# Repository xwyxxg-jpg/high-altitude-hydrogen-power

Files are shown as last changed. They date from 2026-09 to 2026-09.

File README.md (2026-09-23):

# 高寒高海拔 5 kW 氢能移动电源

**High-altitude & cold-climate hydrogen power — 开放设计与研发进度**

面向 −30°C 环境的5 kW净输出燃料电池电源研究项目。当前V2采用纯气态储氢，开展电堆、辅机、散热和氢量的联合计算；历史双储氢方案与R12装配保留为研究记录。

**进度快照：2026-09-23 · 当前计算：V2纯气态储氢 · 历史装配：R12。**
现有结果未证明已达到 5 kW 净输出、120 s 低温启动或寿命指标。

## 最新：V2纯气态储氢联合计算

- [第二版设计与稳态联合求解](designs/v2-gaseous/第二版设计.md)
- [−30℃暖堆稳态、冷液水力与启动热量计算](designs/v2-gaseous/第二版设计_负30度补充计算.md)
- [计算入口、依赖与校验方法](designs/v2-gaseous/README.md)

在暂定4000 m、35℃、4 h任务下，5 kW净输出的基准解需要约6.20 kW堆毛功率、5.20 kW液冷排热及66.2 L气瓶水容积；布局先按2×40 L预留。固定散热器在−30℃环境且电堆已升温时，计入局部伴热及风机预算后毛功率约5.72 kW。上述均为带假设的计算，不是供应商保证或实测；冷浸启动尚未验证。

多项不利假设组合需要约8.15 kW、97.85 A，超过参考7.1 kW/80 A电堆能力，已标记不可行。历史R12 CAD并未按V2重建，不能用于证明V2尺寸。

## 历史R12装配快照

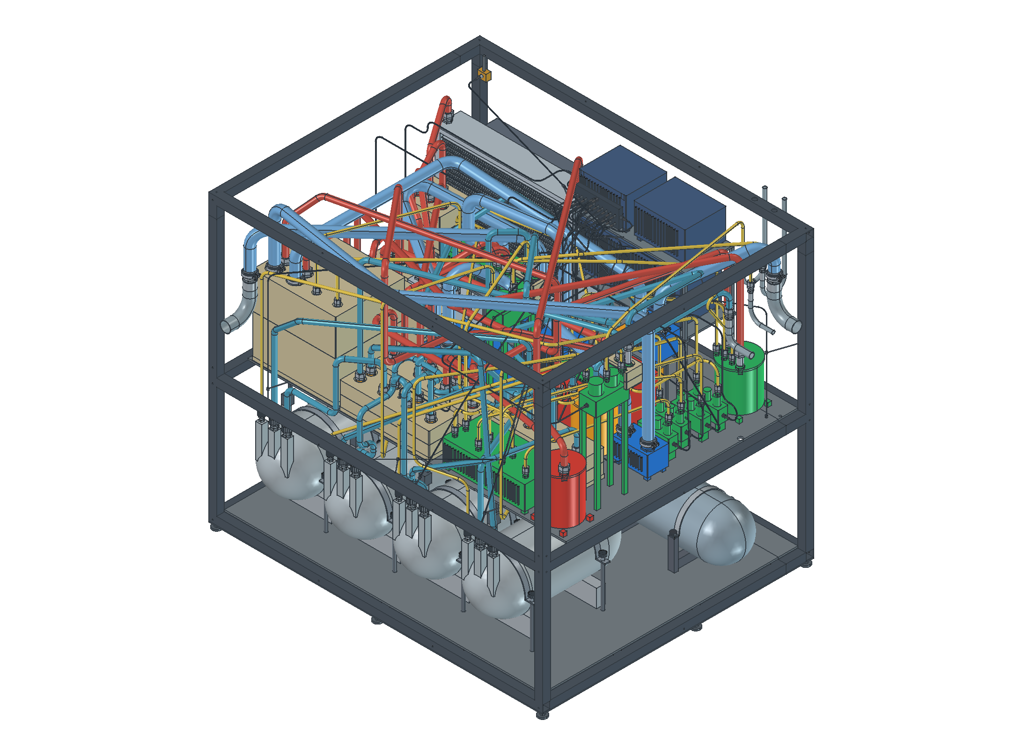
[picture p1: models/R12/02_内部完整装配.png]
R12 内部完整装配


## 历史双储氢方案进展

| 工作 | 已有成果 | 仍待完成 |
|---|---|---|
| 系统设计 | 双氢源、双液路、燃料电池与电池混合供电方案 | 电堆和辅机参数冻结、版本间参数统一 |
| 计算 | 质量/能量/氢耗、海拔工况、PCT 外推与分床热模型源码 | 材料实测参数、模型标定及系统动态仿真 |
| R12 三维布局 | 1011 个零件对象、1203 个实体；外包络约 1724×1458.2×1505 mm | 安装顺序、维护路径与支承强度复核 |
| 管路和线束 | 69 条圆弧管路、21 条线束；126 个内部管端连接检查通过 | 工艺与实物装配验证 |
| 静态几何 | 既有检查记录中超 0.1 mm³ 干涉为 0；STEP 回读实体有效 | 不等同于压力、强度或制造合格 |
| 工具空间 | 112 个接口已筛查，40 个找到无碰撞姿态 | 72 个接口受限；六只容器完整取出路径待复核 |
| 电气设计 | R12 低压电气图、阀门统计 | 与采购定型器件和最终功率基线一致化 |

几何数据来自项目现有 R12 检查记录，本次公开整理没有重新运行 CAD 求解器。

## 研究时间线

| 时间（北京时间） | 思考与决策 | 搜索、计算或校核带来的结果 |
|---|---|---|
| 7 月 18–22 日 | 比较储氢路线，厘清混合能源与冷启动 | 区分局部 CFD 与整机控制；粗算中冷器温升、分水器产水量 |
| 7 月 27 日–8 月 17 日 | 图纸应表达真实连接与控制关系 | P&ID 连通/排版检查；低压电气引脚、CAN 和硬线急停审查 |
| 8 月 30 日–9 月 6 日 | 从容量、耗氧、余热推导零件尺寸 | 空气加热负荷和光管体积被重新修正；发现续航与轻量化冲突 |
| 9 月 9 日 | 查论文、专利和器件，形成完整概念设计 | 70 节方案、质量/能量模型与 FreeCAD 概念装配 |
| 9 月 10–11 日 | 改固态∶气态为 6∶4，压缩布局 | R10→R12；几何检查通过，但 R12 仍有 72 个工具空间受限接口 |
| 9 月 12–14 日 | 检查保温冷启动、重量及报告参数自洽 | 45 min 与 120 s 的定义冲突；区分 70/53/55 节及不同容量版本 |
| 9 月 15 日 | 阀门不能只按电气支线计数 | 逐项核对 14 个对象、52 个外部流体接口 |
| 9 月 19 日 | 公开进展与研究过程 | 重跑概念计算、发布模型及证据，保留未验证项 |

[阅读完整时间线：你的提问与选择、检索来源、计算结果和后续修正](docs/TIMELINE.md)。历史讨论结果按当时工况记录，不等同于实测性能。

## 阅读入口

- [R12 修改与检查说明](models/R12/R12_设计修改与检查说明.md)：当前装配范围、检查方法与未闭合问题。
- [几何与安装校核数据](models/R12/几何与安装校核数据.json)及[接口工具空间检查](models/R12/接口工具空间检查.csv)：可检查的结果记录。
- [9 月 9 日概念设计](docs/concept-design-20260909.md)、[BOM 与接口表](docs/bom-and-interfaces.md)、[参考来源](docs/references.md)。
- [版本与参数边界](docs/STATUS.md)：解释概念设计和 R12 装配的区别。
- [项目思考、检索与验证时间线](docs/TIMELINE.md)：按日期记录方案取舍、搜索依据、计算结果和验证边界。
- [FreeCAD 可编辑模型](models/R12/3D燃料电池模型.FCStd) · [STEP 交换模型](models/R12/R12_紧凑分层_转角修复.step)。
- [电气图源文件](diagrams/electrical-R12.drawio) · [电气图预览](diagrams/electrical-R12.png)。

## 历史双储氢系统关系

```mermaid
flowchart LR
  G[启动气瓶] --> H[氢气调压与供给]
  M[四罐固态储氢] --> H
  H --> FC[液冷 PEMFC]
  A[空气供给与加热] --> FC
  FC --> DC[单向 DC/DC]
  DC --> BUS[48 V 母线与负载]
  B[启动电池] <--> BDC[双向 DC/DC]
  BDC <--> BUS
  FC --> T[主冷却与隔离换热]
  T --> M
  T --> R[散热器]
```

功能图用于阅读；DC/DC 类型、压力与容量应按相应版本文件核对。

## 复算历史概念设计

需要 Python 3.10+ 和 Matplotlib。以下命令在仓库根目录执行：

```bash
python -m venv .venv
# Windows: .venv\Scripts\activate
# macOS/Linux: source .venv/bin/activate
python -m pip install -r requirements.txt
python tools/calculate.py
```

脚本更新 `calculations/parameters.json`，生成分床温度数据及两幅图，并检查能量守恒残差。图表原脚本使用 Microsoft YaHei；未安装该字体的平台可能出现中文字体提示。

计算对应 **2026-09-09 的 70 节概念方案**：156 A、0.65 V/节时毛功率 7.098 kW；变换效率 96%、辅机 1.30 kW 时净功率估算 5.514 kW。该结果不代表实测性能，也不能直接替代 R12 的储氢容量分配。

## 下一步（V2优先）

- [ ] 取得参考电堆高原极化、低温启动和冷却液许可数据。
- [ ] 用泵、风机、散热器及电池实测曲线替换V2假设。
- [ ] 完成纯气态储氢P&ID、接口表和真实器件CAD。

以下为历史R12路线尚未闭合的工作：

- [ ] 统一 R12 装配、技术报告、电气图与概念计算的参数基线。
- [ ] 调整受限阀组和管廊，复核 72 个接口的工具进入路径。
- [ ] 完成储氢模块整件取出路径及 R12 分层支承强度校核。
- [ ] 取得材料 PCT/动力学及阀泵、电堆、高原空气系统的供应商数据。
- [ ] 完成 Fluent 基准/强化床对比和整机低温动态仿真。
- [ ] 通过台架验证冷启动、净功率、热利用率及耐久目标。

## 开源范围

项目原创代码、文档和设计文件采用 [MIT License](LICENSE)。第三方商标、专利及引用资料的权利仍归其权利人；本仓库仅保留来源引用，不分发原始厂商 CAD 库、下载论文和内部参考资料。

这是研究与概念设计资料，不能直接作为压力容器制造或氢系统运行依据。欢迎通过 Issue 提交参数来源、计算修正和装配空间建议；见 [贡献说明](CONTRIBUTING.md)。

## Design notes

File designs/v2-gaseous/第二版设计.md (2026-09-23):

# 第二版设计：纯气态储氢5 kW高寒移动电源

版本：V2.0概念计算版  
日期：2026-09-23  
设计负责人：邢武岳  
状态：完成条件性稳态联合求解；尚未完成供应商选型、低温动态验证及真实三维装配。

2026-09-23补充：[−30℃参数变化与启动计算](第二版设计_负30度补充计算.md)。保留本文件+35℃散热设计点，新增同一硬件在−30℃环境的暖堆稳态、冷液水力敏感性、气瓶温压和启动热量预算；不将暖堆结果当作冷启动成功。

## 1. 本版目标与边界

本版取消固态储氢床、床体供热支路和气固切换机构，采用采购PEM电堆、纯气态储氢、空气供给、单一电堆液冷回路、DC/DC和辅助电池。

**唯一已明确的功率硬约束是对外净输出5 kW。**电堆毛功率必须支付转换损耗和全部计入模型的辅机耗电。旧报告的节数、气固比例、整机85 kg、170 L以及120 s建立气路的定义均不继承。

| 输入 | 本版采用 | 性质 |
|---|---|---|
| 对外连续功率 | 5 kW DC | 用户要求；若改AC需增加逆变损耗 |
| 输出母线 | 48 V，额定约104.2 A | 工程假设，未冻结 |
| 满载续航 | 4 h | 沿用工作假设，可调整 |
| 冷启动环境 | −30℃完全冷浸 | 目标工况，冷浸时间待定 |
| 冷启动时间 | 尽可能120 s；分别记录电池对外供电和电堆建立净输出 | 未证明 |
| 稳态散热工况 | 4000 m、+35℃ | 本版设计假设；不代表电堆已有高原认证 |
| 气瓶额定研究点 | 35 MPa绝压、15℃均温充装状态 | 容量计算参考点；实际充装遵守认证瓶参数 |
| 最低可用压力 | 2 MPa绝压、−30℃ | 调压器输入下限假设 |
| 启动额外耗氢 | 0.03 kg | 预算占位，待动态积分 |
| 储备 | 任务结束保留初始可用氢的10% | 预算假设 |

“5 kW连续输出”不包括电池长期补足电堆功率缺口。电池启动后消耗的电量还需要额外发电余量恢复；本版4 h预算没有包含整段运行中的电池充电任务。

## 2. 功能拓扑

```text
认证气瓶A/B → 各自隔离/切断/安全附件 → 分级调压 → 低压氢路 → 电堆阳极
                                                          ↓
                                               排水/吹扫 → 规定安全排口

空气滤芯 → 鼓风机 → 必要的调温/加湿 → 阴极 → 冷凝水管理/排气

电堆 → 小循环/旁通阀 → 散热器 → 主泵 → 电堆
         ↑ 保温与启动加热       ↑ 膨胀/排气/净化支路

电堆 → 单向DC/DC → 48 V母线 → 外部负载
辅助电池 ↔ 双向DC/DC ────┘
独立安全链/控制器 → 阀、风机、泵、加热器、DC/DC
```

高压排放、低压工艺吹扫和阴极排气的压力、流量与背压限制不同，不能默认汇成同一根细管。图中仅定义功能，不作为施工P&ID。

## 3. 未知量与闭合条件

设计问题本来欠定：没有堆极化曲线、泵风机图谱、散热器性能面和气瓶型号，5 kW不能唯一决定所有部件尺寸。本版引入显式假设，求得一组可复算的初步解，再做敏感性分析。

主未知量为：

- 电堆电流 I；
- 散热器迎风面积 A；
- 冷却液质量流量 m_c。

由三项等式联合求解：

1. 净电功率等于5000 W；
2. 散热器排热等于进入冷却液的热量；
3. 冷却液温升等于5 K。

氢耗、空气流量、风机/泵功耗、气瓶水容积和管径从解中派生。电池、电控箱等缺少定型资料，只给预算及空间占位，不假称由三条方程唯一求出。

### 3.1 采购电堆参考平台

以2026-09-21归档的H-WCS-SP-7K为参考：119节、活性面积200 cm²、80 A、约90 V、公开功率7.1 kW、外形242×200×550 mm、约28 kg。采用现有平台只是为了提供实体尺度。

公开工作环境5～35℃，测试条件65℃、常压及阴阳极100%RH。**这些数据不证明4000 m、60℃冷却出口或−30℃启动时仍有同样性能。**本模型单节0.75 V是基准假设，不是实测极化曲线；0.70 V用于敏感性分析。若低温/高原工作点下降，需要替换输入重算。

### 3.2 功率与反应物方程

```text
Pstack = N × Vcell × I
5000 = ηDC × Pstack − Pblower − Pfan − Ppump − Pfixed
mH2,reaction = N × I × MH2 / (2F)
mH2,fresh = mH2,reaction / ηH2
mair = N × I × MO2 / (4F) × λair / 0.232
```

N=119，ηDC=0.96，ηH2=0.97，λair=2.2，固定辅助电功率100 W。97%是新鲜氢利用率假设，不是阳极流道计量比；若采用氢循环，还要增加循环装置损耗，若死端吹扫则需重新积分排氢。

鼓风机功耗用等熵压缩估计，入口取当地大气压，基准阴极总压升15 kPa，总效率50%。该压升需由滤芯、管路、加湿器、电堆和背压件分项替换；还需要膜两侧差压约束，不能据此直接设置阳极压力。

### 3.3 热管理与液路方程

```text
Qreaction,HHV ≈ N × I × (1.481 − Vcell)
Qcoolant = 0.85 × Qreaction,HHV + Ppump
mc × cp,c × (60−55) = Qcoolant
Δpc = 80 kPa × [液体体积流量 / (20 L/min)]²
Ppump = 液体体积流量 × Δpc / 0.30
```

1.481 V为热中性电压近似常数。85%热量进入冷却液、15%分配给尾气水焓和环境，是尚未测量的分配假设。避免把全部HHV热量与水蒸气焓重复计入。泵电功率保守计入液体，需实机热平衡修正。

暂用低温冷却液温热物性cp=3300 J/(kg·K)、ρ=1060 kg/m³；不等于已指定冷却液型号或确认−30℃黏度/电导率。二次阻力曲线只适合本次温热估算，不能外推到冷浸启动。

DC/DC损耗、风机/鼓风机电机热及电控热没有全部进入电堆冷却回路，应通过各自通风/散热独立排出。整机风道还需考虑热空气回流。

### 3.4 散热器方程

采用ε–NTU逆流基式并乘0.85布局修正，用于初步筛选，不代表实际交叉流散热器。

```text
体积风量 = 3 m/s × A
UA = 1000 W/(m²·K) × A
Qradiator = 0.85 × ε(NTU,Cr) × Cmin × (60−35)
Pfan = 180 Pa × 体积风量 / 0.35
```

这里1000 W/(m²·K)是以**迎风面积**归一的假设UA系数，不是翅片表面对流换热系数。厚度、翅片密度、空气阻力与UA实际相互耦合，必须用同一台散热器性能数据替换，不能独立拼最优参数。

## 4. 基准联合解

| 项目 | 解 |
|---|---:|
| 对外净输出 | 5000 W |
| 电堆毛功率 | 6200 W |
| 电堆工作电压/电流 | 89.25 V / 69.47 A |
| DC/DC损耗 | 248 W |
| 阴极鼓风机 | 259 W |
| 散热风机 | 530 W |
| 冷却泵 | 63 W |
| 固定辅机 | 100 W |
| HHV口径反应热 | 6043 W |
| 电堆尾气/环境热分配假设 | 906 W |
| 冷却液排热（含泵） | 5200 W |
| 冷却流量 | 17.84 L/min |
| 温热液路压降/扬程 | 63.6 kPa / 6.12 m |
| 散热器迎风面积 | 0.344 m² |
| 散热器实际空气体积流量 | 3712 m³/h |
| 散热器出风温度 | 约42.2℃ |
| 反应空气质量流量 | 6.50 g/s |
| 反应空气入口实际体积流量 | 33.6 m³/h（4000 m、35℃） |
| 理论反应氢耗 | 0.311 kg/h |
| 新鲜氢耗（97%利用率） | 0.321 kg/h |
| 反应产水 | 2.78 kg/h，不代表全部在同一分水器收集 |

**功率核对：6200×0.96−259−530−63−100≈5000 W。**

散热器风量与反应空气流量不是一个量级，风机不能混用。散热器面积及风量明显影响寄生功耗，不能把散热风机简单按几十瓦占位。

## 5. 纯气态储氢容量与外包络

使用CoolProp真实氢气状态方程，不用35 MPa理想气体近似：

```text
ρfill = ρH2(15℃, 35 MPa绝压) = 23.995 kg/m³
ρresidual = ρH2(−30℃, 2 MPa绝压) = 1.969 kg/m³
musable,required = (0.32051×4 + 0.03) / 0.90 = 1.458 kg
Vwater ≥ musable,required / (ρfill−ρresidual) = 66.2 L
```

模型按10 L档位向上取整得到70 L。考虑单项不利工况需约73～75 L，本版**布局优先按2×40 L、总80 L预留**，并非已找到或确认某型号气瓶。

总80 L在上述状态下约存1.920 kg氢，可用约1.762 kg。双瓶允许隔离维护与分阶段使用；不意味着可以在带压连接状态直接拆卸。

35 MPa、15℃装满后，同密度冷浸−30℃压力约29.27 MPa，升温至50℃约39.42 MPa。该计算用于暴露温度压力关联，不能解释为允许超额充装。实际允许充装质量、温度补偿和安全附件按认证瓶文件确定。

### 概念尺寸的来源

只做空间估算：假定外径320 mm、容量几何内径280 mm、半球端封几何，再给阀端/端部140 mm长度余量，40 L单瓶外包长度约883 mm。

**320×约885 mm是占位包络，不是压力容器设计图。**内外径差只是几何占位，不代表通过应力核算得到的壁厚，也不能据此制造气瓶。最终采用认证商品瓶的外形、质量、阀口与安装约束。

## 6. 各部件第一轮选型范围与空间

| 部件 | 参数/建议询价范围 | CAD占位外包络 | 确定程度 |
|---|---|---|---|
| 电堆 | 基准6.20 kW毛输出；询价7～10 kW平台 | 参考堆550×242×200 mm；带接管/维护先留650×340×300 mm | 原堆尺寸已归档；实际工况未保证 |
| 气瓶 | 2×40 L，35 MPa研究点，氢气专用认证件 | 每只约885×Ø320 mm；支架/阀区另留 | 纯几何估计 |
| 调压/切断阀组 | 新鲜氢基准0.321 kg/h；暂按0.5 kg/h能力询价，吹扫峰值另定 | 300×250×200 mm | 空间预算，压力级数/料号未冻结 |
| 散热器芯体 | 基准5.2 kW@4000 m、35℃；询价需同时给60/55℃液温 | 芯体约535×642 mm，厚度暂60 mm | 迎风面积由假设模型反算，厚度未求解 |
| 散热器总成 | 3712 m³/h@180 Pa基准；单项不利约5200 m³/h | 650×750×200 mm；恶劣工况需增大 | 含风机/风罩空间预算 |
| 散热风机 | 基准总电功率约530 W，约0.6～1.2 kW询价范围 | 与总成匹配，可能双风机 | 最大/最小转速必须由风机曲线确定，暂不编造RPM |
| 阴极鼓风机 | 6.5 g/s、当地入口33.6 m³/h、压升15 kPa；兼顾30 kPa扫描 | 250×200×200 mm | 占位，需效率/喘振/高原图谱 |
| 空滤总成 | ≥所选鼓风机最大空气需求，压降纳入预算 | 200×150×150 mm；另留150 mm抽芯空间 | 过滤等级、积尘终值、快换结构待定 |
| 主冷却泵 | 基准17.84 L/min@63.6 kPa；询价20～25 L/min@80～120 kPa | 180×130×150 mm | 低温曲线与冷却液资格待定 |
| 膨胀/脱气组件 | 占位0.5～1 L；按系统液量与膨胀率重算 | 150×150×200 mm | 预算 |
| 单向DC/DC | 约80～119 V输入参考范围→48 V；输出≥6 kW，工作点效率≥模型96% | 300×220×120 mm | 必须含开路/瞬态范围、反灌阻断、散热 |
| 电池双向DC/DC | 48 V侧连续功率按启动供电及充电策略确定，暂按6 kW询价 | 300×220×120 mm | 未包含数kW预热同时供电情形 |
| 辅助电池 | 暂0.8～1.2 kWh、低温可用功率≥6 kW；仅对应短时供电，非整堆快速加热 | 400×300×200 mm | 电芯低温曲线、BMS和加热需求未知 |
| 控制/配电箱 | FCU、CVM接口、接触器、熔断、预充、通信及独立安全链 | 350×300×180 mm | 线束和电气原理图后冻结 |
| 氢气检测/排水/泄压 | 响应、量程、低温等级与阀失电状态分别定义 | 随安装位置预留 | 不从零件数量倒推安全方案 |

暂按气瓶40～60 kg、堆28 kg、散热液路12～20 kg、空气氢路8～15 kg、电池12～20 kg、功率电控10～18 kg、框架外壳及附件20～35 kg建立质量预算，总约130～196 kg，不是称量结果。另考虑约2 kg氢及未覆盖附件；建议第一轮整机按**约140～210 kg**评估转运方式。

两瓶平行下置，电堆/电控上置、散热器侧置时，可从**约1200×850×1100 mm**总包络开始试排（约1.12 m³）。它是布局预算，不是完整装配解，不证明维护路径、通风距离或气瓶取出空间已足够。若尺寸目标更小，应由真实部件重排而非缩小占位。

## 7. 管路、接头与传感器

按基准流量限定流速，冷却液1.5 m/s时内径约15.9 mm，先研究16～19 mm内径；空气入口10 m/s时内径约34.5 mm，先研究35～40 mm内径。管网压降还需逐段加入长度、粗糙度、弯头、阀和热交换器阻力。

氢管不能只按氢耗选尺寸：需要同时核对调压瞬态、吹扫峰值、连接标准、最小残压及允许压降。高压段采用合格氢用高压管件组合，低压段单独定义等级。暂不指定材料牌号、壁厚或弯曲半径为已验证值。

参考水冷堆阳极1/2″、阴极和冷却3/4″只表明名义尺寸，不足以判断BSP/NPT或密封形式。每个接头需供应商图纸确认；低压冷却软管也不能用于高压氢路。

| 测量/执行对象 | 第一版接口原则 |
|---|---|
| 气瓶压力 | 选定量程后优先4–20 mA或受支持的数字接口；端口与压力等级随瓶阀组 |
| 低压氢/阴极压力、差压 | 两侧压力及差压都要能验证；量程由堆厂许可窗口确定 |
| 温度 | 堆进出口、环境、关键排水部位；RTD接专用采集模块，不直接假定接CAN |
| 冷却/空气流量 | 输出形式、低温量程和压降由型号确定 |
| CVM与BMS | 获取供应商协议与故障码后接控制器；不假定裸堆CVM自带CAN |
| 氢探测器 | 顶部积聚风险位置与实际通风路径共同确定；安全联锁不只依赖上位机通信 |
| 阀、泵、风机 | 电源、PWM/CAN/模拟量命令、转速反馈和失电状态分别记录 |

每个端口/传感器进入CAD前必须填料号、尺寸、信号、供电、引脚、密封、维护空间和低温范围。

## 8. 冷启动独立预算：尚未闭合

稳态可行不能推出冷启动成功。−30℃至0℃，忽略散热、产水结冰和熔化潜热时：

| 需升温等效热容 | 120 s热功率下界 | 热量 |
|---|---:|---:|
| 5 kJ/K | 1.25 kW | 0.042 kWh |
| 20 kJ/K | 5.0 kW | 0.167 kWh |
| 70 kJ/K | 17.5 kW | 0.583 kWh |

三行都是未知热容的扫描，不能根据28 kg堆重任取一行。应取得电堆组成热容、最小小循环液量及冷启动电化学数据。

若电池在120 s内承担5 kW负载和0.8 kW启动辅机，母线需求约0.193 kWh。按转换效率0.9、SOC使用窗口0.6、低温可用能量系数0.6的假设，名义容量至少约0.60 kWh；因此先给0.8～1.2 kWh占位。功率能力需独立核验，6 kW对小电池是高倍率要求。

若同时增加5 kW电加热，名义能量下界升至约1.11 kWh，母线瞬时功率10.8 kW；若17.5 kW加热，名义容量约2.40 kWh、瞬时23.3 kW。现有6 kW双向DC/DC预算不再适用。不能在模型外默默增加加热器。

应分别输出：电池首次供电时间、电堆首次稳定发电时间、电堆单独维持5 kW净输出时间、启动氢耗、电耗和冰库存。到0℃不作为无冰堵的充分条件。

## 9. 敏感性与不满足条件

| 工况 | 堆毛功率 kW | I/A | 冷却热/kW | 液流/L/min | 迎风/m² | 风量/m³/h | 氢耗/kg/h | 水容积/L |
|---|---:|---:|---:|---:|---:|---:|---:|---:|
| 基准 | 6.200 | 69.47 | 5.200 | 17.84 | 0.344 | 3712 | 0.321 | 66.2 |
| 单节降为0.70 V | 6.371 | 76.48 | 6.146 | 21.08 | 0.406 | 4388 | 0.353 | 72.7 |
| 空气压升30 kPa、散热风阻300 Pa | 7.027 | 78.74 | 5.915 | 20.29 | 0.391 | 4223 | 0.363 | 74.8 |
| 迎风UA系数降至700 | 6.438 | 72.14 | 5.405 | 18.54 | 0.480 | 5187 | 0.333 | 68.7 |
| 上述不利项组合 | 8.151 | 97.85 | 7.956 | 27.29 | 0.707 | 7636 | 0.451 | 92.6 |

最后一行超过参考堆80 A和7.1 kW能力，且超过2×40 L的容量预算，**判为参考配置不可行**，不能当作该电堆的可实现工况。需要提高堆容量、改善流路/散热或降低规定环境下净输出。即使单项工况不过额定上限，也仍缺乏高原极化数据保证。

## 10. 下一步必须补齐的数据

1. 7～10 kW采购平台在60～65℃、低压/高原的极化曲线、允许差压、气体露点及低温资格；
2. 认证气瓶2×40 L或相近组合的实际外形、质量、阀口和充装规定；
3. 散热器在4000 m密度、实际冷却液下的性能面，与风机压流/功耗/转速范围配套；
4. 冷却液低温黏度、冻点、电导率与泵曲线；各元件压降；
5. 电池−30℃的可用功率与能量、加热需要；
6. 停机吹扫、残水和重复冷启动数据；
7. 统一P&ID、I/O表和异常停机逻辑后再做详细CAD。

## 11. 复算与证据

- 脚本：[models/solve_v2.py](models/solve_v2.py)
- 全部数值：[results/solution.json](results/solution.json)
- 自动生成对比：[results/工况对比.md](results/工况对比.md)
- 执行：`python -X utf8 designs/v2-gaseous/models/solve_v2.py`
- 依赖：Python、NumPy、SciPy、CoolProp；实际CoolProp版本写入JSON。
- 求解检查：正值解、求解收敛、三条方程归一残差<1e-7；基准最大绝对残差约2.9e-8 W。数值残差小不证明假设真实。
- 电堆参数证据：[供应商参数来源与局限](SOURCES.md)。本次不把该历史归档当成重新确认的库存或报价。
- 氢物性采用本机安装CoolProp的Hydrogen状态方程；其官方资料入口为 `https://coolprop.org/fluid_properties/fluids/Hydrogen.html`，后续正式报告须归档物性来源与适用区间。

本文件是第二版的主设计记录。新增器件数据后应同时更新输入、联合解、接口表、CAD占位和本文件结论，不只修改文字参数。

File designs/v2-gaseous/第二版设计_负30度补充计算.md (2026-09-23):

# 第二版设计补充：−30℃下哪些参数发生变化

日期：2026-09-23  
版本：V2.1条件性计算  
关联：[第二版设计](第二版设计.md)

## 1. 比较对象：同一台设备，两个阶段

本轮保留V2的5 kW净输出、4000 m海拔、119节参考电堆、两只40 L气瓶、0.344 m²散热器和管路空间。**不重新把散热器缩小成一台只适用于冬季的设备。**

必须区分：

1. **−30℃环境、暖堆稳态：**电堆已成功启动，冷却液保持55～60℃；用来求稳定输出的功率、流量和热量。
2. **−30℃完全冷浸启动：**电堆、液体、泵阀和电池开始时都接近−30℃；先检查流动、启动功率和升温时间。此时不能套用0.75 V/单节或暖液泵曲线。

暖堆模型在同一海拔保持大气压61.64 kPa；它是相同压力边界下的温度对比，不代表真实天气下压力不变。

## 2. 新增未知量、假设与联立方程

散热器迎风面积固定，未知量改为：

- 电堆电流 I；
- 散热器迎风速度 u；
- 暖态冷却液质量流量 m。

仍联立：净功率5000 W、热平衡、冷却液5 K温升。

### 空气与风道

```text
ρair = Patm / (Rair × Tambient)
体积空气流量 = 质量流量 / ρair
Δpradiator = 180 Pa × (ρ/ρ35) × (u/3)²
Pfan,ideal = Δpradiator × A × u / 0.35
UA = UA35 × [(ρu)/(ρ35×3)]^0.7
```

0.7指数为传热随空气质量流速变化的敏感性假设，不是采购散热器实测相关式。固定180 Pa基准也不包含积雪、结霜或滤网堵塞。

理想风机模型在很低风量下得到约1 W，此处**不采用它作实际设备耗电结论**。增加50 W和100 W电功率预算下限进行联立计算；这只是电机/驱动/间歇运行的占位，不证明风机能在所求流量连续稳定运行。

### 保温、局部伴热与进气调温

基准−30℃方案假设：

- 电堆及小循环对环境等效热导UA_shell=3 W/K；
- 阀件、排水及关键局部伴热合计100 W电功率；
- 进堆空气最低温度仅以+5℃占位，最终必须服从堆厂温湿度窗口；
- 稳态所需空气调温从冷却液取热，不另重复计算为电加热。

鼓风机出口温度用同一压升15 kPa、效率50%的压缩模型估计。−30℃入口时出口约+1.2℃，到+5℃只需约23 W。这不包含实际机壳散热、冷管路损失与启动时金属热容；不能由此认定几十瓦伴热足够。

原+35℃模型用同一压缩估计会得到约74.6℃出口，说明原空气系统还可能需要调温。旧模型未完整计算气体调温、湿度和水相变，本轮保留这个缺口，不把它写成已验证系统。

```text
Qcoolant = 0.85×Qreaction,HHV + Ppump
Qradiator = Qcoolant − UA_shell×(57.5−Tambient) − Qair_preheat
5000 = 0.96×Pstack − Pblower − Pfan − Ppump − 100 W固定辅机 − Ptrace
```

伴热预算视为在外部阀件/排水等处分散耗散，未全部返回主冷却液。液体55～60℃的cp、ρ和管网二次阻力沿用V2，以便隔离环境变化；后续需与真实液体物性统一。

## 3. 暖堆稳态联合结果

| 参数 | +35℃ V2基准 | −30℃暖堆，保温+100 W伴热+50 W风机预算 | 变化解释 |
|---|---:|---:|---|
| 对外净功率 | 5.000 kW | 5.000 kW | 硬约束保持 |
| 电堆毛功率 | 6.200 kW | 5.716 kW | 约减少7.8%，取决于辅机假设 |
| 电堆电流 | 69.47 A | 64.04 A | 暖堆单节仍假设0.75 V |
| 电堆电压 | 89.25 V | 89.25 V | **保持的是假设，不是低温实测结论** |
| 环境空气密度 | 0.697 kg/m³ | 0.883 kg/m³ | 同压力下增加26.7% |
| 反应空气实际入口体积流量 | 33.58 m³/h | 24.43 m³/h | 密度增加、电流下降共同作用 |
| 阴极鼓风机电功率 | 258.7 W | 188.2 W | 相同压升下压缩功降低；未计结霜增阻 |
| 散热风机电功率 | 530.3 W | 50 W预算 | 不能当作实际最低可运行值 |
| 冷却液流量 | 17.84 L/min | 16.41 L/min | 暖态流量，不是−30℃冷液流量 |
| 冷却泵功率 | 63.1 W | 49.1 W | 仍为暖液管网假设 |
| 局部伴热 | 原模型未计 | 100 W预算 | 新增电负载 |
| 保温部位对外热损失 | 原模型未单列 | 262.5 W | 3 W/K×87.5 K |
| 从冷却液取出的进气调温热量 | 原模型未单列 | 约22.8 W | 假定风机后气体到+5℃ |
| 散热器排热 | 5.200 kW | 4.499 kW | 主动散热需求仍为数kW |
| 同一散热器所需风量 | 3712 m³/h | 约427 m³/h | 理想传热模型解，不是已匹配风机工作点 |
| 散热器迎风速度 | 3.00 m/s | 0.345 m/s | 需要低风量调节/旁通能力 |
| 新鲜氢耗 | 0.3205 kg/h | 0.2955 kg/h左右 | 由净功率与辅机闭合产生 |

功率核对：

```text
5715.99×0.96 −188.22 −50 −49.14 −100固定辅机 −100伴热 ≈5000 W
```

这里35℃基准未计相同的独立保温/伴热，所以增加“只改变环境空气”的控制算例：毛功率约5.551 kW、氢耗约0.287 kg/h。但该算例采用约1.15 W的理想风机值，不作为工程推荐，只用于分辨模型各项影响。

### 稳态敏感性

| −30℃假设变化 | 毛功率 | 新鲜氢耗 | 含义 |
|---|---:|---:|---|
| 风机预算50 W、伴热100 W | 5.716 kW | 约0.295 kg/h | 本轮示例基准 |
| 风机预算100 W、伴热100 W | 5.772 kW | 约0.298 kg/h | 低速电功率不确定性 |
| 风机预算50 W、伴热500 W | 6.161 kW | 约0.318 kg/h | 伴热可抵消大部分低温散热节电收益 |

UA_shell由3增至10或20 W/K时，满载散热器任务下降至3.887或3.012 kW。由于本算例固定的风机最低电预算，电堆毛功率不变。**这不意味着保温差有利：低载、启动和停机保温时可用反应热更少，环境热损失会成为负担。**

## 4. 冷却液：−30℃启动最大的变化之一

为了量化黏度，使用CoolProp的`INCOMP::MEG-50%`，即50%质量分数乙二醇水溶液。**这只是物性替身，不是批准用于该电堆的冷却液。**普通乙二醇配方的电导率、添加剂和金属相容性可能不符合电堆要求。

| 温度 | 动力黏度 mPa·s | 相对57.5℃ | 比热 J/(kg·K) |
|---|---:|---:|---:|
| −30℃ | 41.77 | 28.97倍 | 3027 |
| −20℃ | 22.18 | 15.38倍 | 3087 |
| 0℃ | 7.93 | 5.50倍 | 3203 |
| 20℃ | 3.69 | 2.56倍 | 3312 |
| 57.5℃ | 1.44 | 1.00倍 | 3492 |

该物性模型的冻结温度约−35.99℃，相对−30℃只有约6 K余量。浓度偏差、局部更低温度和停机环境都会影响可靠性；不能以“低于−30℃”就认定已有充分余量。增加浓度也会改变黏度和换热性能。

### 不把黏度倍率直接当作整条液路压降倍率

补建水力敏感性模型：

- 假设内径16 mm、等效直管长度6 m；
- 管摩阻采用连续跨层流/过渡/湍流的Churchill光滑管关系；
- 将57.5℃、20 L/min总压降校准为80 kPa；
- 余下电堆、散热器、阀等压降，分别假设0%、50%、100%具有随黏度近线性变化的分量，其余按惯性阻力；
- 三种是假设情景，并非统计置信区间，也不能替代真实部件曲线。

| −30℃时未知元件阻力中的黏性分量 | 若强行保持20 L/min所需压差 | 若只能提供80 kPa压差，可达到的流量 |
|---|---:|---:|
| 0% | 约121 kPa | 约15.31 L/min |
| 50% | 约1042 kPa | 约1.58 L/min |
| 100% | 约1963 kPa | 约0.82 L/min |

80 kPa是固定可用压差的比较假设，不是某台泵的实测最大扬程。离心泵低温性能还会因黏度改变，启动电流也未由此算出。

16 mm管内20 L/min时，−30℃雷诺数约689，已处于层流量级。这说明V2温热二次阻力曲线不宜直接用于冷浸启动。表中很高的所需压差只是用来判定流量目标不合理，**不能作为加大泵压、强推液体的建议**；电堆冷却板和密封允许压力可能远低于此。

应优先研究低热容小循环、实际冷却液、低温泵曲线和受控预热，并用真实流量/压差作为升载许可条件。主散热器在启动时隔离，其内部冷液及后续混合的热冲击仍需计算。

## 5. 气态储氢：压力下降，但氢气不会凭空消失

固定总水容积80 L，15℃、35 MPa绝压均温装入同一质量的氢气：

| 均匀气温 | 同质量满瓶压力 | 总氢质量 | 2 MPa绝压残氢 | 静态可用氢 |
|---|---:|---:|---:|---:|
| +35℃ | 37.53 MPa | 1.920 kg | 0.124 kg | 1.795 kg |
| +15℃ | 35.00 MPa | 1.920 kg | 0.133 kg | 1.787 kg |
| −30℃ | 29.27 MPa | 1.920 kg | 0.157 kg | 1.762 kg |

从15℃降至−30℃满瓶压力约降低16.4%，但密闭无泄漏时质量保持不变。静态可用量降低来自规定残压下留在瓶内的氢更多。

V2原容量计算**已经用−30℃、2 MPa残压**，此次不能再对原可用氢重复扣一个低温百分比。

若按本轮暖堆氢耗0.2955 kg/h、0.03 kg启动预算、保留10%可用氢估算，80 L配置的理论任务时间约5.3 h。它未包括实际放气时瓶内温降、调压器流量失调、重启次数和辅助电池回充，因此仍保留4 h任务要求，不据此缩小瓶容积。

调压过程温变不能仅由环境温度或理想气体公式判断。后续需真实气体等焓分析、阀体换热和流量曲线；不要默认所有氢气减压都与普通气体一样降温。

## 6. 120 s冷启动：当前仍有热量约束

使用单节点瞬态模型：

```text
C dT/dt = Qin − UA×(T−Tambient)
Tambient = −30℃，T(0)=−30℃
达到T(120 s)=0℃所需恒定有效热输入：
Qin = 30×UA / [1−exp(−UA×120/C)]
```

分别取UA=3和10 W/K。未加入水结冰/融化潜热、反应产水、内部温差、电化学、低温电池和动态流动带热。

| 需要升温的等效热容 | 达0℃所需有效热功率（UA=3～10 W/K） |
|---|---:|
| 5 kJ/K | 约1.296～1.406 kW |
| 20 kJ/K | 约5.045～5.152 kW |
| 70 kJ/K | 约17.545～17.650 kW |

以有效输入热功率5 kW、UA=3 W/K为例，20 kJ/K节点在120 s后约−0.27℃，70 kJ/K节点约−21.45℃。这是温度计算，不是燃料电池启动试验。

热源功率是进入目标节点的有效热量，不等于加热器铭牌电功率。不能同时把同一部分反应能算作发电和额外“免费”加热。

若要求电池同时供应外部5 kW负载、0.8 kW启动辅机及约5 kW电加热，母线需求约10.8 kW。V2暂定6 kW双向DC/DC不足，应修改电源架构或明确启动期间负载策略；低温电池能否提供这个功率需要独立证明。

### 尚未计算成功的关键项

- −30℃实际极化曲线、膜含水与冰库存；
- 低温辅机启动峰值和泵实际流量；
- 停机吹扫后的残水状态与允许冻融次数；
- 参考采购电堆的低温质保/许可；
- 达0℃后恢复额定净输出所需时间。

因此本轮仍不声明满足“电堆−30℃两分钟达到5 kW净输出”。

## 7. 哪些尺寸不变，哪些设计要调整

| 部件 | 本轮结论 |
|---|---|
| 气瓶 | 仍按2×40 L布局，不因压力变小而换瓶或重复加储量 |
| 电堆 | 外形不变；低温启动资格仍未取得，不能认为暖态功率下降就可以换更小电堆 |
| 散热器 | 保留0.344 m²暖环境尺寸；增加低风量控制、旁通/隔离与寒风穿流分析 |
| 风机 | 不能从427 m³/h直接算RPM；需要最低稳定转速、控制范围和风道阻力曲线 |
| 冷却泵 | 约18 L/min温热选型不足以保证冷浸流量；增加−30℃曲线验收条件 |
| 冷却管路 | 暂保留16～19 mm研究范围；小循环长度、狭窄接口和冷态压降需要重算 |
| 保温 | 新增明确UA目标；例如3 W/K只能作为总体目标，厚度需由面积、材料导热和热桥反算 |
| 局部伴热 | 先按100～500 W扫描；排水阀、尾排、减压阀是否需要及实际功率逐项计算 |
| 排气/排水 | 满载仍有约2.6 kg/h级理论产水；排口、低点、滤芯与冷凝水通路需防积水冻堵 |
| 电池/DC/DC | 暖态稳态尺寸不决定启动电源尺寸；有电加热同时对外供电时可能必须升级 |
| 传感器/接头 | −30℃额定、密封、线缆柔性及温漂需要实际型号确认 |

## 8. 本轮证据与校验

- 脚本：[models/solve_minus30.py](models/solve_minus30.py)
- 结果：[results/minus30_solution.json](results/minus30_solution.json)
- 基准对照：[results/solution.json](results/solution.json)
- 运行：`python designs/v2-gaseous/models/solve_minus30.py`
- 软件：SciPy数值求解与CoolProp物性；版本号保存在JSON。
- −30℃物性来自安装的CoolProp `INCOMP::MEG-50%`；高压氢采用`Hydrogen`。未把通用液体性质当作指定电堆冷却液合格证明。
- 同一固定硬件模型回算+35℃，毛功率与V2相差小于0.001 W；
- 七组稳态工况检查净功率/散热/液体温升残差；
- 18组单节点升温ODE与解析解比较，温度误差小于1e-6 K；
- 三个气温条件下满瓶质量保持不变。

这些检查证明数值实现自洽，不代替采购曲线、整机低温试验和氢安全评审。

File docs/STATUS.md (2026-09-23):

# 版本与参数边界

整理日期：2026-09-23。

| 版本 | 定位 | 参数口径 |
|---|---|---|
| V2 / 2026-09-23 | 当前独立设计：纯气态储氢，固定硬件温度对比 | 5 kW净输出，4 h暂定；35℃基准6.20 kW毛功率，−30℃暖堆约5.72 kW；不是冷启动验证，也不是R12装配参数 |
| 早期 55 节路线 | 历史方案，未作为本次主展示 | 5.577 kW 毛功率不能直接视为 5 kW 净输出 |
| NDS-5K-R1 / 2026-09-09 | 公开的概念报告及可复算模型 | 70 节、7.098 kW 毛功率；固态可用氢 2.16 kg，气态约 0.302 kg，均依赖假设 |
| R12 / 2026-09-11 | 当前收录的三维装配与安装空间检查 | 总可用氢设计值 2.462 kg；固态 1.4772 kg、气态 0.9848 kg，比例 6:4 |
| V4 修订 / 2026-09-13 | 历史对话记录的报告修订口径 | 53 节、182 A、约 6.270 kW；不是本仓库计算脚本的参数 |
| 技术方案比较表统一版 / 2026-09-14 | 按用户指定表格修改第二章和 3.4 节 | 55 节、156 A、5.577 kW；气态 0.72 kg、固态 0.48 kg；未同步重建 R12 |

**时间顺序**：70 节概念设计 → R10/R12 布局 → 53 节报告修订 → 55 节报告局部按表统一。公开仓库保留的是可复算概念方案和 R12 装配研究快照，不代表 9 月 14 日报告参数已通过同一套物理验证。详细动机、计算及修正见 [研究时间线](TIMELINE.md)。

**冷启动定义也发生变化**：早期 120 s 稳定净输出是目标；9 月 12 日受控饥饿与保温讨论改为 120 s 建立条件、约 45 min 升至 0°C 的简化估算。25 mm 保温是该模型下的候选值，不能视为普遍必要厚度，尚不能声明满足原两分钟指标。

两组储氢分配来自不同阶段，尚未在同一个系统模型里统一，不应混算。R12 的几何通过记录不证明概念报告的输出功率和冷启动目标已实现。

原概念报告和参考来源中的 `research/`、历史报告等路径是本地研究归档引用；本公开快照不含这些归档。论文和厂商资料请使用参考来源中的公开网址。R12 说明中旧名 `R12_紧凑分层_转角修复.FCStd` 在本次源目录内实际保存为 `3D燃料电池模型.FCStd`，主页链接采用实际文件名。

已有验证记录：静态实体/管端检查、工具包络筛查、STEP 回读记录。尚缺完整装配路径、R12 强度、低温台架、Fluent 与整机动态验证。本次发布只对材料进行整理、计算复跑和发布校验，不重新背书历史 CAD 检查。

## V2新增计算证据

见[计算入口](../designs/v2-gaseous/README.md)。新增5组稳态设计工况、7组固定硬件温度/辅助功率工况、15组冷液水力情景和18组启动热量情景。氢物性使用CoolProp；暖堆计算、冷液计算和冷启动预算分别记录。保留尺寸占位、性能假设和不可行工况，不宣称达成−30℃120 s启动。

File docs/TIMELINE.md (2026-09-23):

# 项目思考、检索与验证时间线

整理日期：2026-09-23。本文根据项目文件、交接记录和 Codex 项目对话中的用户要求与交付结果整理。日期统一按北京时间（UTC+8）显示，由对话轮次时间戳换算；跨日交付注明日期范围。记录的是你明确提出的问题、要求与决策，以及当时得到的检索、计算和校核结果，不推测未表达的想法。公开版只整理项目相关内容，不上传完整聊天记录。

**阅读口径**：用户要求是研究动机；历史助手回复是对话记录；文献结果属于外部证据；代数/热模型是条件估算；CAD 检查是几何证据；文档校验只证明文件结构或版式。以下各类证据均不自动等同于实测性能。版本冲突见 [STATUS](STATUS.md)。

## 2026-07-18 至 2026-07-19：从参考策略分出局部传热与整机控制问题

**你的问题**：要求结合老师的低温启动策略和技术方案比较表总结路线，并询问“AME 软件”及 Python 自动化如何承担控制和后处理。

**资料阅读与判断**：讨论把 300 系统参考中的传感器自检、小循环保温、电流斜坡、降载恢复用于方案设计，但指出该参考中某阀自检超时本身就是 120 s，不能原样移植到两分钟启动目标。方案比较暂采用气态∶固态＝6∶4，0.72＋0.48 kg；这些是早期输入，后来被多次调整。

**形成的方法**：Fluent/COMSOL 处理床内三维传热与流动；Amesim 或替代系统模型处理氢、热、电和状态机耦合；Python 用于参数扫描、守恒核算和后处理。此时是工具分工与验证计划，没有整机仿真结果。

## 2026-07-21 至 2026-07-22：混合能源架构、中冷器与分水器取舍

**你的问题**：老师强调的混合能源架构究竟指什么；中冷器和阳极分水器是否需要，能否用粗算给出方案。

**资料与计算**：阅读燃料电池无人机混合能源参考，分清供氢侧“双氢源”和电气侧“燃料电池＋锂电池”。在当时低压鼓风机压升约 15 kPa、压缩效率 0.65 的假设下，压缩温升估算对应平原 20°C 进气约 38°C 出气、高寒 80 kPa 环境约 −11°C 出气。讨论据此暂不设独立中冷器、预留接口；这是低压边界下的选型，不适用于任意压比。

55 节工作点的产水量约 0.800 g/s＝2.88 kg/h。假设其中 1%–5% 进入阳极循环，相当于约 29–144 mL/h，支持设置阳极气液分离器；分离水不直接混入低电导率冷却液，保温采用间接换热。比例和储液容积仍为初估，不能当作测量结果。

**后续作用**：为气路、水管理和混合电源图提供计算依据；当电堆、压比和气路改变时须重算。

## 2026-07-27：先把系统图画清楚，再谈计算

**你的思考与要求**：你连续指出设备中心线不能用短线拼接、文字不能覆盖逻辑线、交错位置要清楚，要求图纸按完整系统表达，而不是只把设备堆在页面上。

**完成的检查**：三页系统架构/P&ID 图完成了文字—线段碰撞、缺失端点、非正交线段和微小转折检查；记录结果为 `0`。42 个连接标签移出管线，垂直控制线绕开设备说明。

**验证含义**：这是图纸表达和拓扑连通性的验证，不是流量、压力或设备性能验证。相关成果在 `deliverables/` 的 PDF 和 draw.io 源文件中，公开仓库只收录后续 R12 电气图源文件。

## 2026-07-31：建立第一份项目基线

**你的思考与要求**：要求生成交接文档，保证新对话能够从总体要求、技术路线、关键参数、风险和下一步继续推进。

**形成的技术路线**：5 kW 级液冷 PEMFC；TiFe-Mn 固态储氢床作为主储氢；35 MPa 气瓶负责低温启动；48 V 母线配合锂电池和双向 DC/DC；用 PEMFC 余热预热储氢床。

**当时的计算口径**：55 节、130 cm²、1.2 A/cm²、156 A、0.65 V/节，电堆毛功率约 5.577 kW；理论反应氢耗约 0.0889 g/s；5 kW 连续 4 h 的法拉第积分约 1.281 kg。交接文档同时指出，5.577 kW 是毛功率，不能直接当成 5 kW 净输出。

**验证含义**：法拉第定律、母线电流和功率量级完成了第一版守恒核算；固态床动力学、低温材料数据和系统级冷启动尚未验证。

## 2026-08-17：低压电气架构从“框图”推进到可审查接线图

**你的思考与要求**：要求参考德州仪器/Altium 风格，让低压电气图可读、不过度复杂、交错位置有明确跨线关系、引脚编号符合规范，并要求独立审核。

**完成的设计与检查**：两页图覆盖 48 V/24 V 母线、CAN0/CAN1、FCU/EMS、传感器、执行器、独立硬线急停、P1/P2/P3 引脚、9 路 PT100 和 120 Ω CAN 终端；跨线桥表示不连接，实心点表示连接。审查记录确认图纸标记为概念设计、未放行生产。

**验证含义**：完成了接口、信号和安全链的可读性审查；仍需与最终选定器件、线束长度、屏蔽接地和样机测试统一。

## 2026-08-29 至 2026-08-30：把报告内容写成“方案—证据—待验证项”

**你的思考与要求**：你要求只修改自己负责的章节，保留原目录和 3.1 正文，删除不在原目录内的 3.6–3.8；同时要求把冷启动、固态床接管、EMS、保护链和 Fluent/Python/系统模型/台架验证写清楚。

**完成的文档验证**：3.1 与原始备份逐段一致；3.2–3.5 按原目录重写；批处理 `58/58` 成功；`officecli validate` 通过；视觉复核未发现标题孤立、文字裁切或段落重叠。

**形成的工程边界**：120 s 定义为启动气瓶支持的稳定净输出窗口；固态床接管是随后数分钟的热耦合过程，不能直接写成 120 s 内主床接管。设计值、初步阈值、仿真结果和实测值开始被明确区分。

## 2026-08-30：按容量比例和余热预算推导零件尺寸

**你的思考**：明确气态∶固态为 4∶6，要求先算尺寸再画剖面三视图；空气滤芯要从耗氧和鼓风机流量确定；散热器要从总余热扣除空气和储氢加热需求后确定。

**当时估算**：以 Ø129×384 mm 气瓶、约 4 L 内容积和 23 kg-H₂/m³ 为假设，气氢约 0.092 kg，固态配约 0.138 kg，总量约 0.23 kg。该图是小容量概念示例，不能支撑后来的满功率长续航目标。

空气预热讨论取 −40→+5°C、约 7.6 g/s，理论热负荷约 340 W、设计取 450 W，提出板翅芯体；散热器讨论按 5.0−0.45−0.80−0.12−0.25＝3.38 kW 的余热预算初选 5 kW。其流量、热源温度和分流热负荷均依赖假设，图片生成不证明换热能力。

**后续修正**：9 月 6 日重新审查空气流量与光管尺寸；9 月 9 日概念设计则考虑储氢床不吸热的排热工况，将散热器设计点提高到 10 kW，避免把余热用户持续吸热当作必然条件。

## 2026-09-02：验证 CAD 工具链的基础能力

**你的思考与要求**：先测试拉伸切除和阵列等复杂功能，再决定能否用于项目模型。

**完成的验证**：在长方体上建立直径 10 mm、中心 `(20, 20) mm`、贯穿 50 mm 的通孔；保存并重新读取后，B-Rep 检查确认孔存在且无几何错误。当前 MCP 没有稳定暴露线性/圆周阵列工具，因此阵列被记录为工具能力缺口，而不是假装已经验证。

## 2026-09-03 至 2026-09-06：换热器尺寸从概念外形回到热负荷

**你的思考与要求**：先做一个给进入电堆空气加热的换热器概念模型，再按照换热参数估算尺寸，并把总体参数重新做物理验证。

**建模结果**：入口空气加热器初始包络目标为 `120 × 100 × 80 mm`，实际模型约 `146 × 136 × 80 mm`；通道直径 12 mm，4 条贯通通道建模和复核成功。模型只用于结构和接口测试，未包含完整冷却液流道、翅片、密封和压降校核。

**计算结果**：后续参数复核认为满载空气流量应按约 8 g/s 初选；300 W 换热量约够把 −30°C 空气加热到 0°C，若目标为 +20°C 应按约 500 W 估算；光管管壳式结构难以压到 1.8 L，初步尺寸应预留约 `500 × 120 × 120 mm`（约 7.2 L），若要接近 2 L 需板翅、内翅片、扰流或微通道结构。

**进一步发现**：5 kW 满功率连续约 5 h 需要约 1.9–2.0 kg 可用氢，和早期“轻量双人搬运”设想存在质量冲突；这促成了后续对平均负载、续航定义和储氢模块运输方式的重新审查。

## 2026-09-04：要求展示方案筛选过程

**你的要求**：报告要体现其他对话中的探讨，用表格直观比较各方案特点；随后明确 2.1 只描述边界，比较表从 2.2 开始。

**结果**：报告增加气氢、液氢、甲醇重整、固态储氢，以及风冷、液冷、PCM 和混合电源的比较，将需求、路线取舍和验证流程关联。表格和页面检查通过，但方案比较本身不等于性能已验证。

## 2026-09-09：建立 NDS-5K-R1 概念设计和可复算模型

**你的思考与要求**：按照“主干架构 → 子系统 → 零件 → 型号 → 验证”的顺序完成详细设计，检索论文、专利和供应商公开资料，并把不确定项明确写成待确认条件。

**检索形成的依据**：记录了 TiFe-Mn 工业材料、TiFe 活化、PEMFC 冷启动、金属氢化物换热器、TurboCell 空压机、WIKA 氢压力传感器、Toshiba SCiB、LTC6806、BQ76952、Sensirion 流量计、TCAN1042 和 H2scan 等来源。来源和链接见 [参考文献与检索记录](references.md)。Barale 等工业 TiFe₀.₈₅Mn₀.₀₅ 论文在约 55°C、25–30 bar 吸氢、1 bar 放氢条件下报告约 1 wt% 容量和循环数据；这不直接保证本项目 2 barA 母管下的交付容量。专利检索提供结构线索和权利要求核查入口，不等于已证明本项目创新性或自由实施权。

**概念计算结果**：70 节 × 130 cm²、156 A、0.65 V/节，毛功率 7.098 kW；96% 变换效率、1.30 kW 辅机预算下净功率估算 5.514 kW；考虑 6% 电压衰减后约 5.105 kW；供氢约 0.419 kg/h、77.7 NL/min；四罐固态床按 1 wt% 和 90% 交付率假设可用氢约 2.16 kg，气瓶可用氢约 0.302 kg。

**验证状态**：Python 质量/能量平衡、气瓶库存、海拔空气量和分床热模型可复算，能量残差检查通过；这不是 Fluent、AMESim、整机动态仿真或样机结果。该版本的 70 节是 NDS-5K-R1 概念设计参数，不应自动覆盖其他报告版本。

## 2026-09-09：从材料检索走向参数化三维模型

**你的选择**：发现 SolidWorks 自动化不顺畅后询问 Blender/STEP 兼容性，安装 FreeCAD，要求模型明确气瓶材质、尺寸、电堆格栅、流体接口和鼓风机，并按架构连接管路。

**结果与边界**：当日 V3 交付记录报告 83 个几何特征有效，STEP 回读 439 个实体，包络 3200×1800×1200 mm。分层材料和设备尺寸是概念表达；文件存在、实体有效和管段有起终点，并不证明管网流量、压降或设备内部结构已工程定型。

## 2026-09-10：主动纠正储氢比例并压缩布局

**你的问题与决策**：你先问体积还能否压缩、储氢是否已按固态∶气态＝6∶4；得知当时实际约 88∶12 后，明确要求改为 6∶4、尽量缩体积并加大把手。

**计算和 R10 结果**：总可用氢约 2.462 kg 保持不变，固态分配 1.4772 kg、气态分配 0.9848 kg；按 1 wt%×90% 可交付率，合金约 164.13 kg。R10 包络从前一详细装配约 8.23 m³ 缩至 4.27 m³，约减少 48.1%。记录报告管端和六只容器取出路径检查通过。

**版本限制**：R10 路径检查只适用于 R10 几何。次日 R12 分层和管路改变后，不能继承“完整取出已通过”的结论。这是 R12 仍保留路径待复核项的原因。

## 2026-09-11：R12 三维布局和安装空间检查

**你的思考与要求**：在现有架构和模型基础上做更细的 FreeCAD 装配，连接管路、检查干涉，并进一步压缩布局。

**R12 结果**：外包络约 `1724 × 1458.2 × 1505 mm`，约 3.783 m³；1011 个零件对象、1203 个实体；69 条管路中心线总长约 82.31 m；126 个内部管端连接检查通过；静态干涉检查以 0.1 mm³ 阈值记录为 0 处超阈值干涉；STEP 回读实体有效。

**仍未闭合的验证**：112 个接口中 40 个找到无碰撞工具姿态，72 个受限；储氢模块完整取出路径、全部线束状态下的维修可达性、R12 分层支承强度、压力性能和低温性能仍未完成。R12 储氢分配为固态 1.4772 kg、气态 0.9848 kg、总可用氢约 2.462 kg（6:4），与 NDS-5K-R1 的 2.16 + 0.302 kg假设来自不同阶段，不能混算。

## 2026-09-12：冷启动从两分钟目标转向热平衡核查

**你的明确要求**：“我们还是要使用饥饿法冷启动，要证明的是我们只有加入足够保温材料才可以达成冷启动的条件”。随后又要求检查自己负责章节是否逻辑自洽。

**当时计算**：以等效热容 70 kJ/K、−30→0°C 为假设，显热需求 2100 kJ。有效热源暂取 0.90 kW；若到达 0°C 时无保温散热为 1.08 kW，则该目标温度处净热为 −0.18 kW。在“全程按终温最大散热”简化法下，10 mm 和 25 mm 保温对应约 53.3、44.5 min，形成 25 mm 候选厚度。

**检查带来的修正**：历史回复一度把约 22.8 mm 写成必要厚度门槛；当天后续审查指出，该算法是保守估算，不证明低于 23 mm 一定不能满足 45 min。同组参数采用随温度变化的散热估算时，10/25 mm 分别约 45.4/41.6 min。这些是对话中的条件计算结果，本公开仓库未附该模型的独立复算脚本，不作为定值发布。

**电量与时序核对**：1.3 kW 辅机运行 120 s 约耗 0.043 kWh，而持续 45 min 约耗 0.975 kWh；必须说明电堆何时接管辅机。120 s 建立反应和循环条件、约 45 min 达到解冻升温条件，与“120 s 已满载”是不同命题。受控缺气的可行性仍需单体电压、结冰和耐久数据，热平衡不能证明其可安全实施。

**气瓶问题**：你还要求把水套、瓶口加热和内部翅片论证并入报告。历史估算表明小端口传热不足以快速加热整瓶；−30°C 已有 35 MPa 的固定气量升至 20°C，理想定容压力约为 42.2 MPa。该压力示例不等于常温充至 35 MPa 后冷浸再复温的情况。端口热量除以一瓶还是两瓶热容的数量口径在后续自洽检查中被指出需要修正。

## 2026-09-13：报告图纸和电堆口径出现版本收敛

**你的思考与要求**：你指出报告中图片仍显示旧的 70 节、7.098 kW，要求真正替换图和文字；同时要求把三维模型改为当前整机三视图，删除旧报告版本，并按批注校核负责部分。

**完成的修改与检查**：图 2.1/2.2 更新为当时采用的 53 节、182 A、6.270 kW 口径；冷启动段压缩为明确结论；表 2-1 改为三线表；三视图替换旧模型图；对应批注校验后删除，报告结构和页面验证通过。

**验证含义**：这是报告交付口径的统一过程，说明 70 节概念模型、53 节报告修订和早期 55 节路线并存于不同阶段；不能把它们拼成一个“已冻结”参数集。

## 2026-09-13：质疑体积与重量能否达到汇报目标

**你的问题**：“800×550×420 这个尺寸可能吗”；“重量可能是 84～86 kg 吗”，并要求尝试最高质量储氢密度材料计算。

**可以直接核算的结果**：该外包尺寸为 184.8 L；R12 约 3783 L，两者相差约 20.5 倍。R12 的 1.4772 kg 固态可用氢在 1 wt%、90% 利用率假设下，仅合金就约 164.13 kg，已超过整机重量目标。

**高容量材料假设的边界**：按 7.6 wt%×90% 得到约 21.6 kg 仅是容量代数，不能证明该材料在本项目低温和 PEMFC 余热温度下能放氢。原回复给出的极限轻量化范围和可缩至某尺寸的建议，没有对应完整新模型，不列为已验证结果。结论是当前 R12 配置与这些目标冲突，需要改容量、材料、工况或布局；不能据此宣称所有 5 kW 系统都不可能小型化。

## 2026-09-14：按技术方案比较表强制统一负责部分

**你的思考与要求**：要求以 `技术方案比较V2.xlsx` 为准，强制修改自己负责的第二章和 3.4 节，并重新保存、去除 AI 写作痕迹。

**当时采用的报告口径**：55 节、156 A、5.577 kW 毛功率；气态 0.72 kg、固态 0.48 kg、总量 1.20 kg，气态∶固态 6:4；启动电池 0.30 kWh；整机约 800×550×420 mm、84 kg、170 L；空气计量比 4、空气质量流量 12.26 g/s。

**验证含义**：文档按指定表格统一并通过结构和版式校验，但这些数字属于报告提交口径；更早的 9 月 9 日 NDS-5K-R1 和 9 月 11 日 R12 使用不同设计边界。9 月 14 日是报告局部按表统一，不代表已用新参数重算 R12。800×550×420 mm 的外包体积实际为 184.8 L，历史回复同时列出的约 170 L 尚缺不同体积口径的解释。

## 2026-09-15：从阀门数量改为逐接口核对

**你的要求**：先统计阀门，再明确指出“不能合并接口，按照建模里面的挨个查看，具体写清楚连的哪里”。

**核对结果**：[逐项连接清单](R12-valves.md)整理 14 个阀门、阀块及止回汇流相关对象的 52 个外部流体接口，按“本体接口→管路编号→对端设备→对端接口”列出；另列 63 根内部管路和 13 条阀类电气支线。

**纠正的认识**：13 条电气支线不能等同于 13 只物理阀门；组合阀内部未拆开的隔离、比例、止回和减压功能仍需细化。`Mix` 为低压氢气计量切断部分，`TV2` 属于主液散热旁通，阴极背压阀不能当作阳极排氢阀。这是模型接口核对，不是实物阀数量的最终采购冻结。

## 2026-09-19：公开进度、复跑计算并补充时间线

**你的要求**：阅读项目文件，创建开源仓库展示当前进度，并阅读其他对话，按时间补充思考、搜索与计算验证。

**公开发布**：2026-09-19 创建 `high-altitude-hydrogen-power` 公共仓库，收录 R12 图像/模型/校核记录、概念设计、计算源码、电气图和本时间线。公开仓库明确把静态几何检查和性能验证分开，并保留待验证问题。首轮发布重跑了 [计算脚本](../tools/calculate.py)，输出参数与原归档一致；这次时间线更新不重新运行历史 CAD 或冷启动模型。

## 目前可以认为已经验证的内容

1. 需求、方案取舍、报告章节和图纸拓扑有可追溯的讨论记录。
2. Python 概念级质量/能量/氢耗计算可以复算，核心守恒检查通过。
3. 电气图、P&ID、CAD 和 R12 的若干结构/连通性检查有输出文件支撑。
4. 公开仓库中的源码、参数、图片和报告入口可以从同一版本读取。

## 目前不能宣称已经验证的内容

1. −30°C 下 120 s 内达到 5 kW 净输出。
2. TiFe-Mn 在目标温度、压力和流量下的真实 PCT、动力学、放氢速率及 20% 提升。
3. 5 kW 净输出、热利用率提升 50%、千小时衰减不超过 6% 和低温故障率不超过 3%。
4. R12 全部接口可维护、储氢模块可完整取出、结构强度和压力容器符合制造/法规要求。

## 来源对照

- 项目交接与技术基线：`PROJECT_CONTEXT.md`、`PROJECT_HANDOFF_20260829.md`、`PROJECT_HANDOFF_20260830.md`
- 概念设计：`新设计/01_系统详细设计报告.md`、`新设计/tools/calculate.py`、`新设计/calculations/parameters.json`
- R12 装配：`新设计/FreeCAD_详细装配/R12_紧凑分层与圆弧管路/R12_设计修改与检查说明.md`
- 对话结果：2026-07-27、07-31、08-17、08-29/30、09-02/03/06、09-09、09-13/14 的项目对话记录

### 对话来源索引与可公开复核的证据

以下名称按任务原名记录，长标题保留应用显示的省略号。只公开项目内容的摘要，不附私人对话链接、账户信息和本机临时路径。没有公开原始脚本的历史计算，明确按“对话记录”使用。

| 来源任务 | 本次使用的日期/内容 | 公开证据 |
|---|---|---|
| 读取一下PPT和PDF的要求，理解一下目前的调研内容，完成理解后回复已经理解，并且简单介绍一下了解 | 7 月 18–31 日需求、参考策略、能源架构、P&ID；8 月报告整理 | 历史对话及本地交接记录；不公开原始参考资料 |
| /goal 请你看一下交接文件，按照德州电气的这个风格画一下低压电气架构图，保证可读性高，不能过于复杂，在交错位置画清… | 8 月 16–17 日电气图审查 | 历史对话；[后续 R12 电气图](../diagrams/electrical-R12.drawio) |
| 设计构件三视图与层叠 | 8 月 30 日容量、空气及散热预算；9 月 9 日 FreeCAD | 历史对话；概念外形不作为实测证据 |
| 高寒地区氢能移动电源技术方案报告-V1.docx按照目前的规划填写一下我需要做的，只有明确标记邢武岳负责的部分才可以 | 9 月 2–6 日建模、方案对比和参数复核 | 历史对话及本地参数汇总 |
| 设计系统并输出详细报告 | 9 月 9 日概念设计、资料检索和自动化模型 | [概念报告](concept-design-20260909.md)、[来源](references.md)、[源码](../tools/calculate.py)、[参数](../calculations/parameters.json) |
| 请你阅读一下新系统架构图.pdf以及E:\High attitude fluent Cell\新设计，参考一下E:\H… | 9 月 9–15 日 R9/R10/R12、紧凑性、接口核对 | [R12 检查说明](../models/R12/R12_设计修改与检查说明.md)、[检查数据](../models/R12/几何与安装校核数据.json)、[阀门接口](R12-valves.md) |
| 评估低压电气架构 | 9 月 9–14 日气瓶加热、保温、报告计算及版本调整 | 历史对话；文档结构通过与物理验证分别记录 |

本时间线是已读取相关轮次的研究摘要，不声称每个任务的所有工具输出均已重审。关键数值保留工况和版本；进一步实测或重算时应追加结果及对旧结论的修正，不覆盖研究过程。

## 2026-09-23：纯气态储氢V2与−30℃计算

**设计要求**：改为纯气态储氢，以5 kW对外净输出设置未知量，联合估算主要部件，再比较−30℃工况。

**模型**：联立净功率、散热和冷却液温升求电堆电流、散热器面积及液流量；低温对比固定散热器面积，改求风量。使用真实氢物性核算气瓶容量与温压，并分开处理冷液黏度和启动热容量。

**结果**：35℃基准毛功率6.20 kW，−30℃暖堆含伴热预算约5.72 kW；多项不利组合超过参考电堆能力。50%质量分数乙二醇示例在−30℃的黏度约为57.5℃的29倍，不将其当成供应商合格冷却液。两分钟启动仍取决于电堆真实热容、水冰管理与启动电源能力。

**发布范围**：原创Markdown、Python和计算结果；不发布第三方完整产品网页、手册或供应商CAD。见[V2计算与复算入口](../designs/v2-gaseous/README.md)。

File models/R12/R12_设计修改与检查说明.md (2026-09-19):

# R12 紧凑分层与圆弧管路修订说明

本次完成全部管路的固定圆弧重建、分层布局压缩、接插件朝向调整和线束重排。外包络体积从 4.265 m³ 降至 **3.783 m³**，减少 **11.3%**。管路转角和静态几何检查通过；整机安装可行性尚未闭合，因此本版是安装空间复核版。

## 1. 尺寸与布局

| 项目 | R10 | R12 |
|---|---:|---:|
| 机架长×深×高 | 1700×1440×1640 mm | 1700×1380×1500 mm |
| 包含收起把手、管口和通气立管的外包络 | 1724×1504×1645 mm | 1724×1458.2×1505 mm |
| 包络体积 | 4.265 m³ | 3.783 m³ |

后部采用散热器、电池和控制器分层布置，控制器与 DC/DC 位于电池上方。氢水换热器、混水阀和部分阀组采用独立托板抬高布置。机架深度缩短 60 mm、高度缩短 140 mm，封闭底板、上下层隔板、分体外壳及加大折叠把手均保留。

储氢模块外形和容量沿用 R10：可用氢总量 2.462 kg，其中固态 1.4772 kg、气态 0.9848 kg，质量比例为 **6∶4**。本次没有用缩减储氢量换取体积下降，也没有把 R11 的储氢单独试排当作整机尺寸。

## 2. 管路转角与连接

63 条内部管路和 6 条外部管路全部采用直线与相切圆弧构成的中心线。69 条管路均为单一有效空心实体，管端圆弧后的直段均不少于 32 mm，中心线总长约 82.31 m。

| 管路 | 外径 | 中心线圆弧半径 | 建模依据 |
|---|---:|---:|---|
| 内部氢路 | 12 mm | 38 mm | 12 mm 管手动弯管器的名义半径 |
| 储氢换热水路 | 22 mm | 33 mm | 预制弯管，按 R=1.5D 估算 |
| 主冷却水路 | 26 mm | 39 mm | 预制弯管，按 R=1.5D 估算 |
| 内部空气路 | 46 mm | 69 mm | 刚性预制弯管，按 R=1.5D 估算 |
| 外部空气管 | 54 mm | 81 mm | 刚性预制弯管，按 R=1.5D 估算 |
| 排放及通气管 | 18 mm | 54 mm | 按 R=3D 估算 |
| 外部补液管 | 28 mm | 42 mm | 预制弯管，按 R=1.5D 估算 |

12 mm 管的 R38 依据为 [Swagelok MS-HTB-12M 产品参数](https://products.swagelok.com/en/c/hand-tube-bender/p/MS-HTB-12M)。其余数值是本次理论设计采用的预制管件尺寸，不能直接当作任意材质软管的允许折弯半径。

新增 112 组可拆活接或空气卡箍；储氢模块的 14 个断开接口补成固定半体、端面密封圈、管侧半体和滚花解锁套。126 个内部管端的截面连接检查全部通过。14 个解锁套的 14 mm 回缩行程均无碰撞。该结果只证明接头回缩空间，未证明完整储氢模块的取出过程。

## 3. 线束与实体检查

重新布置 20 条传感器及阀门支线和 1 条主干线。线束圆弧按静态安装 R=6D 估算，补齐 42 个接插件应力释放护套，并增加 13 个连接到真实结构面的中间线夹。几处朝向相邻阀体的接插件改为侧向或上向出线，汇接盒增加侧向接线位置。

最终模型含 1011 个实体零件对象、1203 个实体。检查以 0.1 mm³ 为相交体积阈值：原管路模型完整检查与修改后模型的差异检查共同覆盖全部零件对，结果为 0 处超阈值干涉。复用原检查结果时要求对应零件的 BREP 序列完全相同；新增和变化的零件重新检查。管路与线束之间另用 1 mm 中心线采样，并扣除 1.01 mm 采样误差余量。

STEP 重新导入后仍为 1203 个有效实体，总实体体积相对误差 7.79e-09。FreeCAD 展示文件与检查模型的实体几何一致，已保存中文名称、颜色和打开时的内部装配视图。

## 4. 安装空间的实际结论

112 个上部接口完成工具包络筛查：**40 个找到无碰撞姿态，72 个未找到无碰撞姿态**。逐项结果与遮挡零件列在《接口工具空间检查.csv》中。

活接按 220 mm 长开口扳手、60 mm 径向进入距离、30° 转动范围及 70×60×50 mm 手部包络检查，同时放置反力扳手。除对置姿态外，还检查了独立夹角。空气卡箍按两侧套筒、刀杆和手部包络检查。该工况假定外壳、可拆保温层及线束尚未安装，接头可按记录方位装配；它不是带全部线束状态下的维修可达性证明。

主要遮挡集中在散热器前的混水阀及温控阀、回水汇管、储氢供回水阀组，以及部分跨越设备的管段。电池上方堆叠虽然降低了整机高度，也使背压阀附近需要先完成管路连接再安装电池。仅列出拆装顺序不能代替连续安装路径检查，本版未把这些接口标为安装合格。

继续修改时，先把混水阀、温控阀和回水汇管转到可抽出的侧向检修托板，再把跨越阀组的管段集中到固定管廊；随后校核最终闭合管段的进入路径及两把扳手的操作空间。储氢模块还需完成“断开管路和电连接—移开压带—避让框架—整件取出”的连续路径复核。在这些问题解决前，不再继续压缩外壳尺寸。

## 5. 文件与视图

- `R12_紧凑分层_转角修复.FCStd`：可编辑的 FreeCAD 装配文件；默认隐藏外壳以显示内部，外壳零件仍保留。
- `R12_紧凑分层_转角修复.step`：通用三维交换文件。
- 01～07 图片：整机外壳、内部完整装配、分层元器件布局、圆弧管路与接口、线束固定点、储氢断接细节、散热器与风扇。
- 3 份 CSV：管路圆弧与直段、线束与固定点、接口工具空间。
- `几何与安装校核数据.json`：尺寸、路径、接口、检查结果及源文件校验值。

R10 源模型未被覆盖。当前模型用于本科创新比赛的理论方案与三维展示，不能将本次几何通过结果写成整机装配或压力性能已经验证。

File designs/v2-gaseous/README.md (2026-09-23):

# V2：纯气态储氢5 kW电源计算

日期：2026-09-23。此目录包含原创设计记录、可复算Python模型与生成结果。当前为带假设的概念计算，未证明采购电堆的高原/低温能力，未完成V2实际CAD或台架验证。

## 阅读顺序

1. [第二版设计](第二版设计.md)：目标、未知量、闭合方程、基准结果、容量、部件尺寸占位与敏感性。
2. [−30℃补充计算](第二版设计_负30度补充计算.md)：暖堆稳态、冷却液黏度/压降、气瓶温压与启动预算。
3. [来源与限制](SOURCES.md)：采购数据时间、物性工具与公开范围。

## 复算

从仓库根目录执行，建议使用Python 3.12独立虚拟环境：

```bash
python -m venv .venv
# Windows PowerShell: .venv\Scripts\Activate.ps1
# macOS/Linux: source .venv/bin/activate
python -m pip install -r designs/v2-gaseous/requirements.txt
python -X utf8 designs/v2-gaseous/models/solve_v2.py
python -X utf8 designs/v2-gaseous/models/solve_minus30.py
python -X utf8 designs/v2-gaseous/models/verify_results.py
```

必须先运行`solve_v2.py`，因为负30℃模型读取它生成的基准硬件参数。脚本按自身位置写入本目录`results/`，不会修改历史概念计算。

发布时验证环境：Python 3.12，NumPy 2.4.3，SciPy 1.17.1，CoolProp 8.0.0。

## 输出与覆盖范围

| 文件 | 内容 |
|---|---|
| `results/solution.json` | 5组稳态设计条件；包括参考堆额定能力与80 L气瓶容量检查 |
| `results/工况对比.md` | 稳态设计结果表 |
| `results/minus30_solution.json` | 7组暖堆工况、15组水力情景、18组启动热量情景和3组气瓶温度 |

脚本内包含求解残差与启动ODE/解析解检查；`verify_results.py`进一步核对电/热平衡、原工况复现、固定面积、气瓶质量守恒和不可行标记。这些只能验证实现自洽，不能代替实验标定。

−30℃环境下暖堆需要约5.72 kW毛功率是条件性结果，依赖50 W风机预算和100 W伴热等假设。它不代表−30℃冷堆能直接输出功率，也不意味着散热器可以缩小。原R12图纸和模型属于历史双储氢路线，不是本目录的三维验证。

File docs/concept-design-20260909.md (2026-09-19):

# 高寒高海拔 5 kW 氢能移动电源系统详细设计报告

版本：NDS-5K-R1｜设计与检索日期：2026-09-09

设计基准：《新系统架构图.pdf》与 PROJECT_CONTEXT.md。设计顺序：主干架构、子系统与零件结构、零件型号、全系统参数复核。

本文是一份可进入供应商技术交流、建模和样机评审的工程概念设计。计算结果、供应商公开参数、设计目标和待验证条件分别标注，不将已有研究的结果写成本项目实测结果。配套文件包括部件选型表、可复算脚本、参数JSON、结构示意图、来源摘录与检索记录。

## 1 设计结论、范围与验收边界

### 1.1 推荐方案

保留主架构图中的四只固态储氢罐、两只气态储氢瓶、液冷PEMFC、两台冷却泵、两只电子节温器、液—液隔离换热器和A/B、C/D、E/F三组伴热接口。系统采用“四罐分批升温、两气瓶启动补差、两个独立液路、48 V混合电源”的撬装平台。

为补足高原辅机功耗及寿命末期输出余量，电堆采购规格由旧版55节改为70节、单节有效面积约130 cm²，156 A、0.65 V/节对应7.098 kW毛功率。48 V输出仍限制在5 kW连续，额外能力用于辅机和性能衰减裕量。70节是本次新增设计值，不是现有电堆实物参数。

燃料电池接口由纯Boost改为具有输入反向阻断的单向升降压DC/DC。原因是70节开路电压可能超过48 V，旧版55节开路也可能出现同样问题；纯Boost不能覆盖完整输入范围。氢母管则建议由原0.30—0.50 MPa不明压力口径改为0.20 MPa绝压低压缓冲，阳极入口另设跟随阴极的压差调节。两项修改均保持原图的功能关系，解决实际接口不匹配。

### 1.2 主要参数总览

| 项目 | 本次设计基线 | 状态与限制 |
|---|---|---|
| 外部输出 | 48 VDC、5 kW连续，45.6—50.4 V | 目标；AC输出另计逆变损耗 |
| 环境 | −30℃冷浸；0—4000 m额定；5000 m边界分析 | 海拔为新增工程假设，原项目未给高度 |
| 运行温度范围 | −30—+20℃额定设计，+40℃作为降额验证点 | +20℃用于避免只在严寒下核算散热 |
| 电堆 | 70节×130 cm²，156 A，45.5 V，7.098 kW毛功率 | 定制采购规格，极化曲线未冻结 |
| 系统功率余量 | 辅机1.30 kW、变换效率96%时净5.514 kW | 代数估算；平均单体衰减6%后约5.105 kW |
| 主储氢 | 4×60 kg TiFe-Mn合金，约2.16 kg工程可交付氢 | 以1.0 wt%容量、90%利用作假设，必须核验压力窗口 |
| 启动储氢 | 2×6.8 L、35 MPa氢气专用复合瓶 | 可用氢约0.302 kg，非空气呼吸器瓶替用 |
| 满载氢耗上界 | 0.419 kg/h，约77.7 NL/min新鲜氢 | 70节156 A，氢利用率98%，不含外泄漏 |
| 续航 | 氢容量预算约5.29 h，已扣10%运行储备 | 不计电池延长续航；非验证值 |
| 阴极空气 | 9.78 g/s，约454 NL/min，λ=2.5 | 正常λ=2—2.5须堆厂认可；λ=4将显著加大辅机 |
| 主/次液路 | 主30 L/min，储氢15 L/min | 温热额定；冷启动按黏度限速 |
| 散热器 | 最不利规定工况下10 kW热排散设计点 | 高原曲线与风扇工作点待供应商保证 |
| 电池 | SCiB 20Ah-HP候选，20s2p，46 V/40 Ah/1.84 kWh | 低温120 s功率需验证 |
| 冷启动 | 系统≤120 s达到≥4.5 kW并稳定10 s | 电池辅助与FC自主两套指标分别报告 |
| 运输形态 | 四罐可拆卸、小型撬装/带制动推车 | 整机约430—540 kg，不能双人搬整机 |

### 1.3 原始硬指标逐项处理

| 需求 | 设计响应 | 当前证据状态 |
|---|---|---|
| −30℃最低放氢温度 | −30℃环境启动由气瓶供氢，固态床受热后供氢 | 若要求床芯全程−30℃且无外热，TiFe-Mn主线不满足 |
| 传热速率提高20% | 同质量同边界下比较夹套基准与内翅片强化床 | 已定义结构与验证方法，未取得CFD证明 |
| 平均放氢速率提高20% | 同SOC、压力、热输入和放氢区间比较 | 需PCT与动力学实测，不能由UA增加直接推定 |
| 热利用率提高50% | 规定等效任务、计入预热及泵耗的热利用指标 | 目标待验证，防止将零基线用于相对提升 |
| 1000 h衰减≤6% | 控制反极、冻融与膜含水，预留功率裕量 | 只能通过耐久试验验证 |
| 低温故障率≤3% | 硬线保护、诊断与重复试验 | 明确故障/需求次数口径后统计验证 |
| 启动≤2 min | 冷启动电池、启动气源、低热容小循环、局部加热 | 整机能量预算合理；FC结冰/电压恢复仍未验证 |
| 完整仿真结果 | 本次提供0D质量/能量核算和分床热模型 | 不冒充Fluent、AMESim或样机结果；题目完整仿真仍需后续完成 |

要求中的“储氢瓶最低放氢温度−30℃”与PROJECT_CONTEXT中的受热床体40—55℃运行存在语义冲突。本报告不擅自删除原始要求：环境−30℃下受热放氢是主方案；床芯−30℃直接放氢是尚未闭合的独立材料要求。若后者为强制验收项，应启动不同PCT材料筛选，而不能宣称目前TiFe-Mn设计已全部满足题目。

### 1.4 项目阅读与版本裁决

检查了项目根目录、deliverables、output/pdf中的相关资料，已对其中47个Markdown、PDF、Word、Excel文件建立提取清单。主要阅读对象是需求、最新架构、两版现有技术报告、低压电气交接、材料调查、参数验证、阀泵需求和300系统冷启动策略；旧报告备份及派生图纸用于查版本差异。CAD实物尺寸和应力状态未通过SolidWorks打开验证；软件工具仓库、诊断日志和与氢能项目无关的演示文件只作范围识别，不视作工程依据。清单见research/local_inventory.json。

优先级：本次用户指令与原始题目 → 主架构图的功能拓扑 → PROJECT_CONTEXT的有效路线 → 近期物理核算 → 历史报告与参考样机。发生参数冲突时，以守恒关系和已核实供应商/论文原文为依据，在本报告明确提出修改。

| 旧资料问题 | 本次处理 |
|---|---|
| 55节5.577 kW等同5 kW净输出 | 用辅机预算重新定电堆，55节只作为对照 |
| 0.30—0.50 MPa未区分绝压表压 | 所有气路压力带A/G；阳阴极差压单独控制 |
| 10℃、0.20 MPa即可并联至更高母管 | 改为床压力高于母管及阀压损，同时通过负载流量资格试验 |
| 1—2 L气瓶只算120 s用氢 | 按首床预热等待、失败重试和剩余压力重新定为2×6.8 L |
| 热管理12—15 L/min直接沿用 | 重新按6.59—9.08 kW堆热量计算，主路提高至30 L/min |
| 水泵表63—262 L/min、10 W电源条目 | 前者为大系统水力边界，后者明显是低压控制侧，不能当泵总耗电 |
| 氢换热器表最高3.92 g/s | 本项目额定约0.116 g/s，按热负荷缩放，保留材料/洁净要求 |
| 气罐129×384 mm、双源“4比6”旧尺寸 | 缺少容量和压力闭合，不能作为新设计装配外形 |
| 300系统−0.5 V、>260 V及22 kW空压机 | 只借鉴状态机，禁止移植电压门槛和功耗 |
| PCM可长期防冻/冷浸后有热量 | 仅作短时余热缓存；完全冷浸后不提供免费启动热 |

## 2 文献和技术路线依据

### 2.1 储氢路线选择

35 MPa气氢具备可靠供氢响应和较好的系统质量性能，适合启动及轻量备选；液氢依赖20 K级储存和专用补给，5 kW装置不采用；甲醇重整增加热启动与CO净化负担，也不作为两分钟低温启动主路线。TiFe-Mn允许在温和温度下回收低品位废热，并提供储氢瓶强化传热的研究对象，因此保留为比赛研发主线。

选择TiFe-Mn并不意味着它比气氢更轻。其优势在工作压力、模块化储放氢及结构研究空间；长续航的质量代价必须计入。AB5材料可以作为成熟对照，但同样不能仅依据“常温可逆”推定−30℃供氢。

### 2.2 可直接支撑设计的论文证据

Barale等的工业TiFe0.85Mn0.05论文全文已下载核验[L1]。其公开结果为55℃、约25—30 bar吸氢、1 bar放氢条件下约1.0 wt%可逆容量，并考察250次循环；活化粉末表观密度约3.28 g/cm³。重要限制是这些条件不同于本项目2 barA母管和240 kg床体，不能把1.0 wt%不加验证地当成新系统保证容量。

Dematteis等全文[L2]给出成分变化对平台和滞后的影响。s6第一平台的解吸焓熵约30.6 kJ/mol、103 J/(mol·K)，第二平台约35.2 kJ/mol、126 J/(mol·K)。数据支持低温必须考虑平衡压力，也支持以成分和批次PCT进行材料验收。不能混合不同平台参数拟合单一全程放氢曲线。

Dreistadt等摘要[L3]给出工业粉末活化的强温度依赖：所研究条件下，90℃方案的孕育时间约0.84 h，50℃方案约277 h。首次活化应在供方或专用工艺台架完成，不在野外启动过程中现做。活化后密封运输、污染控制与批次再验收必须写入采购要求。

Luo与Jiao的冷启动综述[L4]用于组织膜含水、冰堵、产热、吹扫的分析框架；Lototskyy等综述[L5]用于金属氢化物与燃料电池应用路线比较。两篇此次核验了题录，未获得完整开放全文，不将其中未经复核的数值作为设计定值。

### 2.3 新近研究的适用范围

此次通过Crossref检索到2023年快速冷启动实验研究[L6]、2025年辅助加热策略分析[L7]、2026年PEMFC结构优化[L8]、2026年分支翅片[L9]与螺旋翅片储氢研究[L10]。这些记录用于指导后续模型选题和文献追踪；目前仅核实题名、出版记录与DOI，出版商正文未成功取得，不能据题名推断提升比例。

本项目优先研究可制造的轴向换热管＋横向分段导热片，而不一次叠加泡沫金属、纳米颗粒、复杂螺旋和拓扑结构。每次增加一种强化措施，都要同时比较合金装填损失、渗透率、制造成本和氢气污染风险。

## 3 第一阶段：系统主干及接口设计

### 3.1 总体构型

NDS-5K-R1由发电核心母座、四个固态储氢抽屉、双气瓶框架和独立散热风道组成。核心母座包括电堆、空气供给、阳极分离/循环、主液冷、功率变换、启动电池和电控。四个床体独立隔离，气源合流前各自完成防倒灌；液路按单罐选择加热，避免启动时把240 kg合金全部接入热负载。

正常功率路径：电堆 → 源端熔断与接触器 → 单向升降压DC/DC → 48 V母线 → 输出保护 → 外负载。LTO电池经独立双向DC/DC接入母线。EMS维持平均电池功率接近零，电池只承担启动与短时动态，不能长期填补毛功率不足。

主架构图中的红色低电导率液路与黄色储氢液路通过HX-301换热隔离，保持两个膨胀空间。次回路允许使用常规经材料兼容性确认的防冻液，主回路必须燃料电池专用低电导率介质，二者不能共用补液罐或回流管。

### 3.2 主架构图逐项映射

| 原图对象 | 新位号/设计 | 处理 |
|---|---|---|
| 固态储氢瓶1—4 | MH-201—204，4×60 kg合金 | 保留4支路，补独立液路阀、流量资格判断与泄压 |
| 气态储氢瓶1—2 | GH-205—206，2×6.8 L/35 MPa | 保留2支路，补双级减压、超流切断、PRD |
| 比例阀1—6 | PCV-201—206 | 仅作低压配流，不直接承担35 MPa降压或安全切断 |
| 电堆及CVM、FCU | STK-101，CVM-101，FCU-101 | 70节选型，70通道单体检测 |
| 中冷器 | HX-101双模式空气调温器 | 保留位置；冷态预热、热态冷却/旁通 |
| 氢气换热器A/B | HX-201，B为热供、A为回液 | 额定0.15 kW、峰值0.25 kW |
| 阳极分水器C/D | SEP-201，D为热供、C为回液 | 气液腔与伴热夹套不连通 |
| 空气换热器E/F | HX-101，F为热供、E为回液 | 独立限流；不能让气路接进冷却液 |
| 冷却泵1/2 | P-301/P-401 | 主30 L/min、次15 L/min |
| 电子节温器1/2 | TV-301余热分配/TV-302散热旁通 | 加阀位反馈与失效旁通 |
| 水箱 | TK-301密闭膨胀脱气罐 | 排口不是正常敞口溢流；补次路TK-401 |
| 去离子器 | DI-301旁路 | 旁流0.3—1 L/min，不让主流全部串过滤芯 |

原图黄色管线经过两气瓶，容易被理解为给35 MPa瓶体整体加热。本设计将该处明确为瓶阀/减压器受控伴热站，并设置可锁闭旁通。高压瓶壳不主动加热，除非瓶厂书面允许并给出限温、均匀性与充装压力校核。

### 3.3 气路压力分层

所有绝压以A结尾、表压以G结尾。环境压力由PT-001实测，不能将4000 m工况仍按101.3 kPaA处理。

| 层级 | 初始设计范围 | 保护/控制原则 |
|---|---|---|
| 高压瓶侧 | 35 MPa充装等级；接口按认证组件最高允许压力 | 氢专用瓶阀、PRD、管路、一级减压器 |
| 一级降压侧 | 约0.6—1.0 MPaG | 独立超压释放，第二级入口压力能力匹配 |
| 固态床承压侧 | 充装约2.5—3.0 MPaA，工作压力依PCT变化 | 每罐独立承压设计，最高可信温度/充装故障决定设计压力 |
| 合流缓冲侧 | 0.18—0.22 MPaA，设定0.20 MPaA | 气瓶稳压，床支路PCV缓慢分担 |
| 阴极入口 | 约环境+20 kPa，排气与堆压损另核算 | 质量流量优先，低压差堆需厂商确认 |
| 阳极入口 | 阴极入口+5—10 kPa | 初步压差闭环；暂按±20 kPa保护窗口讨论，不是厂商限值 |

床体并联需P床≥P母管＋阀管压损＋控制余量，初始资格线为0.27 MPaA，且最冷有效测点≥52℃、出口90 NL/min短时资格试验合格。流量资格试验必须在接近实际背压下进行，不能对大气放空测得后直接认定可供堆。0.27 MPaA不是材料平台的保证值；实际门槛由PCT、压损及衰减情况修正。

如果堆厂要求阴极高于0.15 MPaA且空压机功耗明显超过预算，或阳极入口必须0.30 MPaG以上，应整体重算空气功率和床体可用氢量，不能只调一个压力设定值继续使用本设计。

### 3.4 主干连接表

| 回路 | 明确连接顺序 |
|---|---|
| 气瓶支路×2 | 瓶阀/超流保护→高压切断→一级减压→级间泄压与测压→二级减压→低压比例阀→止回→合流母管 |
| 固态床支路×4 | 床出口粉末过滤→压力温度检测→独立常闭切断→比例配流→止回→母管；安全泄压直接取自容器 |
| 合流至阳极 | 缓冲容积→新鲜氢计量→HX-201→主切断与阳极压差调节→电堆 |
| 阳极回流 | 电堆阳极出口→SEP-201→氢循环泵→阳极入口；分离器底部排液/排氢接独立安全排放 |
| 空气 | 防雪罩→空滤及压差→压缩机→HX-101/PTC/旁通→质量流量→截止阀→阴极→背压阀→疏水尾排 |
| 主液冷 | TK-301静压补给→P-301→电堆→热供母管→受控小循环/HX-301/散热器及三条限流伴热支路→回液→P-301 |
| 次液冷 | TK-401→P-401→HX-301→选择阀→当前床夹套/内管→回液总管→P-401；停用床支路隔离 |

分水器回流是为提高氢利用率补充的功能支路，主图未画出。初版若采购允许死端阳极的堆，循环泵可取消，但必须重新确认吹扫氢耗并扩大储氢预算，98%氢利用率不能继续自动沿用。

## 4 第二阶段：子系统与零件结构

### 4.1 电堆及空气系统

STK-101采购要求：额定点70×0.65×156，−30℃冷浸启动试验数据、有效热容、可用含水窗口、极化曲线、阳阴极压差限值、供氢纯度、流量/计量比、冷却液要求、开路电压上限和连续冷启动次数。以在本报告环境和压差条件下的保证毛功率定型，而不是以宣传页“7 kW”定型。

130 cm²是延续项目的单节面积，156 A对应1.20 A/cm²。不能因此假定低压、−30℃、寿命末期仍有0.65 V；实际运行由电流、最低单体、氧气供给和热状态共同限幅。7.098 kW工作点是尺寸核算上界，5 kW负载时可降低电流以减氢耗。

空气按9.78 g/s、4000 m−30℃39.9 m³/h、+20℃48.1 m³/h估算；留污染和调节余量后，采购在实际入口状态下12 g/s、约60 m³/h能力。总增压初值25 kPa，其中堆入口相对环境20 kPa，其余覆盖滤芯、换热器和管路；压降分配最终服从供应商曲线。

CTi-1100官方目录给出1.5 kW、压比1.9、17 g/s、总等熵效率55%、质量3.9 kg。它是曲线询价候选，不是已确认额定匹配件；高原折算转速、喘振/堵塞边界、供电范围、−30℃启动能力均待核实。若实际工作点需要1.5 kW连续，1.3 kW全辅机预算将失效，应换用更合适的低压比机型或提高电堆功率。

HX-101设计成空气调温器，正常空气走气侧、主冷却液走液侧，配置电PTC和旁通。9.78 g/s空气由−30℃升至+20℃需约491 W，因此选0.6 kW热交换和0.5 kW电加热等级；压缩机自身增温会降低实际加热需求。不得恒定打开加热器而忽略压缩机出口温度。热态空气高于目标时可换热冷却，若冷却液温度高于空气则旁通，不能把“中冷器”名称当成任何工况都有冷却能力。

紧凑板翅芯体目标约220×160×60 mm，安装包络280×220×140 mm，实际换热面积和翅片密度由ε-NTU及压降设计。空气口DN40，空气侧额定压降≤0.8 kPa，液侧支路1—2 L/min。它取代旧光管管壳式约7 L包络是结构方案变化，不能宣称仅缩短原管束即可达到同样换热量。

### 4.2 固态储氢床及内构件

每个MH-201—204采用可拆卸金属氢化物承压罐，概念内径240 mm、有效筒段长665 mm，对应约30 L内腔。单罐装60 kg合金；按活化粉末3.28 kg/L占18.3 L，加入约3 kg膨胀石墨后，混合料、内管、翅片和膨胀空间需共同闭合。采购时按实测压实密度和吸氢体积膨胀重新确认装料，禁止把30 L全部塞满粉末。

本体设计采用内置8根轴向冷却管、分段薄导热片、中心多孔集氢管和外夹套。优先选择直管结构以便检漏、加工和更换；气体在粉床中流向中心集氢管，冷却液在封闭内管及外夹套内循环，两介质严禁直接混合。

| 子零件 | 概念规格 | 功能与验证重点 |
|---|---|---|
| 承压筒/封头 | 氢兼容316L；内径240、有效长665 mm | 壁厚、封头、焊接、疲劳按压力容器设计确认，本文不给生产壁厚 |
| 内换热管 | 8×外径10 mm，约640 mm有效长 | 管材及连接需承受气侧对液侧最高差压；不能按液压单侧选厚度 |
| 横向导热片 | 约60片、厚0.5 mm、约10 mm轴向间距、分瓣带补偿槽 | 受控导热路径约5—10 mm；防粉化挤压和氢化膨胀 |
| 集氢管 | 中心多孔316L管，外径约16 mm | 导气、过滤、独立出口，防细粉迁移 |
| 导热增强介质 | 膨胀石墨起始5 wt%混合比例 | 与0%、2.5%对照，测导热率/渗透率/容量损失 |
| 端部过滤 | 两级可更换烧结过滤元件 | 过滤等级以粉化粒径分布决定，初选2—5 μm精滤 |
| 膨胀缓冲 | 分段装料、弹性限位、预留空间 | 不靠压紧提高导热而牺牲吸氢膨胀裕量 |
| 绝热层 | 约25 mm可拆卸绝热层＋防潮罩 | 单罐等效散热系数目标≤1.5 W/K |
| 温度测点 | 每罐中心/中径/外缘×前中后，9点 | 4罐共36点；不能用全系统9点覆盖四罐的最冷区 |
| 支路液路阀 | 每罐供/回可隔离，带平衡与止回 | 当前罐优先、剩余余热预热下一罐 |

铝导热片具有较轻质量，但须验证与合金、氢气及污染物的兼容性；片材不作为承压边界，采用机械接触时必须测接触热阻。若采用铝与钢钎焊或复合连接，其工艺能力和污染风险需单列鉴定。所谓“导热率4—8 W/(m·K)”和单罐UA≥300 W/K均是目标，不是可从加5%石墨直接获得的已知值。

按筒体、封头、内构件、阀件、绝热及液体合计单罐75—90 kg预留。安装包络约直径300 mm、长900 mm。每罐采用滑轨与机械吊点，不允许依靠软管或气接头承重。四个60 kg合金罐是保持满功率长续航的样机规模；进行CFD和低温传热对照时，先做5—10 kg等特征长度子样，再验证尺度放大。

### 4.3 传热基准与强化结构

基准B0：相同合金批次和净装量、相同承压容积、单外夹套、无内部强化翅片；强化B1：外夹套＋8根直管＋分段翅片；B2：B1加2.5%石墨；B3：B1加5%石墨。保持入口液温、流量、初始温度、初始储氢量和出口背压一致。质量相同试验外，还要补充同安装体积试验，避免只在取消膨胀空间后取得表面优势。

主比较指标为达到同一床芯温度的时间、10—90%相同解吸区间的平均放氢量、最低供氢压力及床内最大温差。UA只用于缩减建模，不直接代表放氢速率。若缺少动力学，报告只给传热改善，不能给“放氢提升20%已完成”。

### 4.4 高压气瓶、减压及氢气换热器

GH-205/206分别6.8 L、35 MPa，必须为氢气用途认证总成。优先交替使用并轮换待机，保留另一路独立可用性；每路具有自己的减压、止回和切断。常压气体排放、气瓶PRD放散和冷却罐呼吸/泄压分开布置，不能用一个普通小管收集所有泄放口。

两级减压前后的压力、流量、温度监控覆盖最低残压2 MPa及高压满瓶。氢气在此温压范围的节流温变不能简单照搬空气“必然降温”的说法；主要防冻风险包括环境冷浸、密封/执行器性能、湿气及阀座污染。采用实气状态方程和减压器试验确定温变及加热需求。

新鲜氢约0.116 g/s，取cp≈14.3 kJ/(kg·K)，−30℃升至40℃仅约116 W显热，故HX-201取150 W额定、250 W峰值。不使用原大系统数千瓦氢加热器。换热器紧凑不锈钢焊接双介质结构、气侧额定压降≤3 kPa、液侧0.3—0.5 L/min，气侧承压覆盖减压失效后的受保护最高压力。选双壁或可监测中间层结构，以限制冷却液进入燃料电池造成污染。

### 4.5 水分离与阳极循环

SEP-201采用旋流/重力分离＋防冲击挡板，概念气液腔0.3—0.5 L、可检测液量50—100 mL；排水阀最低点布置，短直排水段带伴热。理论整堆产水3.67 kg/h，不等于阳极分离器必须处理全部产水；设计同时核对阴极疏水路径。

循环泵额定回流目标50—100 NL/min湿氢，差压5—15 kPa，功耗≤60 W作为询价起点。回流量由堆厂阳极计量比确定，新鲜供氢与循环氢分别计量。停机及急停程序防止空气倒入阳极和氢气进入电气舱；不向湿氢循环管随意接入环境空气吹扫。

### 4.6 双液路及散热

主回路温热工况30 L/min、压差初估50—80 kPa，泵电功率预算160 W。泵与过滤、换热器、堆、阀的压损必须在同一流量上叠加；−30℃黏度高时按实际泵曲线限流，小循环初选4—6 L/min，不以“流量大”作为冷启动目标。防冻液按供应商质量/体积分数定义配比，目标冻结保护≤−40℃；“55%乙二醇”不能脱离定义直接等同冰点−45℃。

次回路15 L/min、5 kW换热等级，单罐可接全部次路流量，回路设置旁通避免所有床阀关闭时泵憋压。HX-301低电导率侧必须低离子析出；优先不锈钢焊接/镍钎焊或合格隔离设计，普通铜钎焊板换不直接进入主回路。一次侧约65→60℃，二次热供约60—63℃；5 kW换热功率必须在这组小端差下保证，不能引用大温差目录额定值。

散热器在床体不吸热、外部+20℃、4000 m工况下仍需容纳堆热上界约9.08 kW，并留到10 kW设计点。若空气允许升温20 K，10 kW约需0.50 kg/s空气，4000 m、+20℃下约2450 m³/h。散热风机按工作静压而不是自由风量选型，建议双风机总工作风量≥2500 m³/h；若风机电耗超过200 W预算，须相应重算电堆余量。外形先预留700×500×150 mm核心和独立风道。

去离子旁路0.3—1 L/min，温补电导率目标≤5 μS/cm、超过10 μS/cm报警。膨胀罐与泵入口建立静压，主路冷态预充压力初值30—50 kPaG并按最高温校核；绝压必须高于介质蒸汽压及泵NPSH要求。主液总量目标4—6 L，启动参与换热容积≤1.5 L，具体受电堆内部容积约束。

### 4.7 电气、启动电池与局部PTC

FC-DC/DC输入建议20—85 V、输出48 V、连续8 kW、输入至少200 A，单向供能并有可靠反向阻断。70节在开路状态按每节1.1 V上界约77 V校核；正常45.5 V时主要升压，轻载时可能降压。启动电池双向DC/DC输入30—56 V、48 V侧连续8 kW/峰值12 kW不少于120 s，峰值电流和持续时间同时写入合同。

BAT-101初选40只SCiB 20Ah-HP，20串2并，46 V/40 Ah/1.84 kWh。官方单体质量约545 g，电芯总质量21.8 kg，成包按30—36 kg预留。官方1900 W输出是25℃、SOC50%、10 s、由内阻推算的数值，不用于证明−30℃120 s能力。−30℃可用容量暂按60%敏感性假设，实际启动前由BMS允许功率决定。

PTC分为电堆小循环3 kW、空气0.5 kW、阀与分离器合计0.2 kW。每路具有温度传感、独立温控熔断/限温及流量许可；没有液流时禁止液体PTC通电。停机保温的PCM只作为可选约1—2 kg热缓存，完全冷浸启动预算按其零可用潜热处理。

控制电使用独立熔断和后备支路，急停切断供氢、PTC和外部主功率后仍可维持氢检测、必要通风和日志。不得出现主接触器断开后要求已失电的风机继续吹扫的逻辑矛盾。

## 5 系统控制、启动与故障保护

### 5.1 控制分工及速率

FCU管理堆、电流许可、气液执行器；EMS管理负载分配和电池SOC；BMS自主保护电池；CVM逐节检测70节；硬线安全链不依赖CAN。拟用CAN0连接功率变换与BMS，CAN1连接温压流量与执行器；总线两端各120 Ω终端、支线短接，模拟地与动力回流分开。

建议DC/DC内环由其厂商控制器实现；FCU气路状态采样10—20 ms，CVM整体刷新≤20 ms，温度/热管理100—500 ms，床体调度1 s。传感器可达速率应先验证，不在CAN拥塞或滤波过长时仍使用0.2 s保护延迟。安全跳闸硬线输入应具有独立响应时间要求。

### 5.2 冷启动时序与两个成功判据

| 阶段 | 动作及退出条件 | 异常处理 |
|---|---|---|
| S0冷浸待机 | 记录停机干燥状态；冷浸达到温度稳定 | 无可用低温电池功率则报告不能启动 |
| S1唤醒0—2 s | 后备控制电、氢检、绝缘、SOC、阀位和接口互锁 | 安全异常锁止，不以软件绕过 |
| S2液路2—8 s | 小循环低流量、局部PTC、分离器/排水阀解冻 | 干转/冰堵中断PTC和加载 |
| S3气路8—14 s | 气瓶供氢、压力建立、阴阳极压差及空气流量闭环 | 压力建立失败切气，限制自动重试次数 |
| S4受控反应 | 从堆厂允许的小电流开始，约2—5 A/s初值，允许保持/回退 | 单体恢复失败关载，不直接跳到156 A |
| S5启动资格 | 120 s内输出≥4.5 kW，母线合格持续10 s | 同时保存电池、FC、辅机功率，超时记录失败 |
| S6形成余热 | 堆出口/入口温度及电压稳定，再逐步开放HX-301 | 冷液冲击时减少余热输出 |
| S7首床接管 | Tmin≥52℃、P床≥0.27 MPaA、流量及持续性合格 | 20—30 s平滑并联；不合格立即回气瓶并降额 |
| S8后续分床预热 | 保证当前床解吸热，再用剩余余热加热下一床 | 剩余气瓶时间小于预热需求时提前限功率 |

系统启动判据沿用PROJECT_CONTEXT，但单独计算FC净贡献P_FC_net=ηP_stack−P_aux。严格燃料电池启动试验要求P_FC_net≥4.5 kW持续10 s且电池平均功率不为正；母线由电池供4.5 kW只能证明混合电源可供电，不能证明PEMFC已完成冷启动。120 s应从用户启动指令开始，不能将预热、自检从计时中扣除。

启动斜率10 A/s源于300系统的特定试验，不能移植为本项目保证值。初始标定以较低斜率起步，逐步试验电压、产水与温升，最终斜率、保持段和超时由样堆数据决定。不能为抢时间容许反极而同时声称满足1000 h低衰减。

### 5.3 分罐调度算法

床体状态设为COLD、WARMING、QUALIFY、SUPPLY、RESERVE、FAULT。估计每罐可供氢量和剩余预热能量，以“最小预热能量＋足够可用容量”选下一罐。液路优先保障SUPPLY罐的放氢吸热，其后向WARMING罐供热；气瓶维持母管压力，床阀控制流量或逐步开度，避免六只比例阀同时各自追同一压力导致振荡。

资格判断不只看温度。检查P床−P母管余量、出口流量、新鲜氢总需求、最低温点及其下降率。单罐全额供氢能力不足时，优先两罐并供，气瓶补瞬态。首罐并联时间由模型和实测输出，不在控制器写死6分钟接管。气瓶可用氢不足时禁止新一轮冷启动，而不是只看压力大于2 MPa。

### 5.4 停机、水管理与急停

正常停机先卸外负载、降堆电流、控制排液，再按堆厂膜含水窗口执行吹扫；记录累计吹扫量、湿度/压差和残水估计。排液后局部伴热延时关闭，隔离高压气源，关闭外部输出。过度干燥也会使下次启动电压下降，不能以最长吹扫时间作为最优策略。

氢泄漏达到0.4%vol初步预警，1.0%vol初步跳闸；传感器布置于储氢舱与堆阳极接头区域高点。跳闸先禁止继续供氢并硬线断开源端切断阀/PTC/外部输出，保留后备氢检测与安全通风。不会为了“吹扫”在泄漏舱继续开氢。断电后PRD仍有效，不由电磁阀隔离容器与泄压装置。

### 5.5 初步保护参数表

| 对象 | 初步动作 | 需确认事项 |
|---|---|---|
| 单体电压 | <0.55 V持续0.5 s降载；<0.45 V持续0.2 s关载 | 沿用项目保守初值；堆厂低温专用窗口优先 |
| 反极 | 任一可靠检测到反极立即关载并锁止诊断 | ADC误差、线束开路与滤波不掩盖反极 |
| 氢/空气差压 | 按堆厂上下限立即限流/关载 | ±20 kPa仅为询价初值，不是通用膜强度 |
| 堆出口温度 | 目标65℃，70℃进入保护 | 是否允许短时70℃须厂家批准 |
| 床体 | 55℃目标；60℃减热；65℃关供热并降额 | 同时监测压力；不能只关液路而忽略继续升温 |
| 泵/液流 | 低流、失速、干转禁止加热和加载 | Δp有压不等于有流量，必须双判据 |
| 绝缘 | 启动前与运行中监测，阈值按实际系统绝缘协调 | 若母线接地，IMD方案需重新评估 |
| 通信丢失 | 关键节点100—500 ms按功能进入安全状态 | 各执行器失联默认状态写入协议 |
| 电池 | 低温允许功率与单体下限限制负载/PTC | SOC≥50%不能代替允许功率校核 |

## 6 第三阶段：仿真、试验与证明链

### 6.1 0D/1D系统模型边界

系统级模型建议先用Python验证守恒，再迁移到OpenModelica/Simscape/Amesim。每个子模型必须有输入、输出和可辨识参数：

| 子模型 | 输入 | 输出 | 首要校准数据 |
|---|---|---|---|
| PEMFC极化/产热 | 电流、氢/空气压力、温度、湿度 | 电压、热、氢耗、产水 | 5点极化曲线及−30℃启动曲线 |
| 空气压缩机 | 入口P/T、转速、阀位 | 质量流量、压比、功率 | 含滤芯和换热器的地图 |
| 氢床 | PCT、动力学、UA、装料状态 | 压力、放氢流量、热负荷 | 5—60℃PCT和恒温/恒流t90 |
| 液冷 | 泵曲线、阀位、黏度、热容 | 流量、压降、各节点温度 | −30/20/40℃泵与换热器曲线 |
| 电池/DC/DC | SOC、温度、功率限 | 母线电压、电流、热 | −30℃允许功率脉冲 |
| 控制状态机 | 传感器、故障注入、负载 | 阀/泵/PTC/DC/DC指令 | HIL时序和保护延迟 |

模型输出不能只给一条漂亮曲线。每个工况还要输出氢质量闭合、能量闭合、母线偏差、最低单体、床体最冷点、保护事件和失败原因。PCT、热容、UA、气路压损未冻结前，结果只能叫“参数扫描”或“设计筛选”。

### 6.2 储氢床Fluent/COMSOL建模计划

第一阶段使用三维共轭传热、固体多孔等效导热、液侧湍流/层流及容器外保温，不加入未经测量的放氢源项；第二阶段以实测PCT和Arrhenius参数加入质量源项；第三阶段将四罐切换和母管压力降阶成系统模型。网格独立性至少三档，目标量为床体平均温度、最冷点温度、出口流量和换热功率，网格加密后关键指标变化小于3%。

几何对照：B0外夹套；B1八管＋分段片；B2增加2.5 wt%石墨；B3增加5 wt%石墨。每一模型同时导出合金净装量、压降、液体体积、制造复杂度。以10%、50%、90%解吸量对应时刻计算平均放氢速率，传热速率以相同热输入下床体有效焓升除以时间定义。只有B1/B2/B3相对B0均满足边界和重量约束，才允许选择强化方案。

### 6.3 当前计算的可复现结果

本报告的`tools/calculate.py`已经运行通过，生成`calculations/parameters.json`、`bed_model.json`、`bed_warmup.png`和`pct_screen.png`。参数为设计筛选，不是实验数据。

| 量 | 结果 | 如何解读 |
|---|---:|---|
| 70节、156 A、0.65 V毛功率 | 7.098 kW | 作为净5 kW和辅机余量的电堆上限工作点 |
| 变换效率96%、辅机1.30 kW净功率 | 5.514 kW | 需以真实压缩机/散热风机核验 |
| 假定电压衰减6%后 | 5.105 kW | 仍只是一阶线性敏感性，不是耐久证明 |
| 新鲜氢 | 0.419 kg/h、77.7 NL/min | 包含2%未利用氢，未含泄漏和吹扫实际增加 |
| 理论产水 | 3.67 kg/h | 分配到阳极/阴极后另行处理 |
| 4000 m、−30℃空气体积 | 39.9 m³/h | λ=2.5、9.78 g/s初值；+20℃为48.1 m³/h |
| 堆反应热（HHV口径） | 9.08 kW | 设计散热器按10 kW，实际需用供应商效率核算 |
| 床额定吸热 | 1.80 kW | 以31.2 kJ/mol、理论氢流率计算 |
| 4床60 kg、1 wt%×90% | 2.16 kg氢 | 支持约5.29 h含10%储备的代数预算 |
| 2×6.8 L、35 MPa启动瓶 | 0.329 kg充装，0.302 kg可用 | 1.22压缩因子、2 MPa残压假设，需瓶厂校核 |
| 床预热简化模型UA=100/200/300 W/K | 第一罐约21.5/16.5/15.7 min | 4罐全部约78.1/80.9/81.7 min；可用热5 kW、单罐45 kJ/K、52℃门槛 |
| 床供氢温度筛选 | UA=200/300时供氢罐最低约52.0℃ | UA=100只有约43.9℃，按当前筛选不合格 |
| 能量启动筛选 | C=18 kJ/K、8 kW有效产热约125 s含24 s流程 | 只证明热量可能，未包括冰堵、含水和电压恢复 |

这里采用70节而不是55节，直接体现了主干设计必须先做系统净功率闭合。若采购只提供55节，当前模型明确给出约4.05 kW（辅机1.30 kW、效率96%）的净功率，不能称5 kW额定，除非实际辅机低于约0.38 kW或运行电压明显高于初值。

### 6.4 冷启动验证矩阵

| 试验 | 工况 | 记录 | 通过条件 |
|---|---|---|---|
| 电池单独供电 | −30℃冷浸，SOC 50/70/90% | 母线、DC/DC、电池温度、允许功率 | 控制器和阀泵完整唤醒，不发生BMS保护 |
| 气瓶点火 | −30℃，瓶压2/10/35 MPa | 减压出口、阀体温度、流量 | 14 s内低压母管合格、无结冰与超压 |
| 电堆受控升载 | −30℃、0—156 A多斜率 | 70节单体、堆进出口温、空气/氢压 | 120 s内FC自主净功率≥4.5 kW并稳定10 s |
| 防冰循环 | 低温、高湿，含水模拟 | 分水器液量、排水阀、尾排压降 | 无流路堵塞；停机后规定时间排尽残水 |
| 首罐接管 | 床−30℃、气瓶供电起步 | 36点温度、床压、母管、阀位 | P床余量、52℃最冷点、资格流量连续满足 |
| 负荷突变 | 0.5↔5 kW、0.5—2 kW/s | 母线、FC/电池功率、最低单体 | 母线不越45.6—50.4 V，保护不误动作 |
| 故障注入 | 漏氢、断流、压力传感断线、阀粘连 | 硬线与软件时间戳 | 按矩阵在规定时间内切氢、PTC、外部输出 |

### 6.5 储氢性能验证

材料入厂：成分、粒径、XRD、氧/水污染和装料密度；材料级：5—60℃、0.05—3.5 MPa PCT，至少三次升降压循环及高/低平台；床级：绝热、定温、恒热流和恒出口背压四类放氢试验；模块级：−30℃冷浸后气瓶预热、四罐顺序接管和压力释放试验。

传热提升20%的验收采用：

`R_T = (t90,B0 − t90,Bx) / t90,B0`

平均放氢提升20%采用相同10—90%氢量区间、相同出口压力和平均输入热量的：

`R_m = (m_dot_avg,Bx − m_dot_avg,B0) / m_dot_avg,B0`

热利用率50%采用：

`η_heat = Q_to_desorption / (Q_stack_available − Q_pump − Q_fan)`

比较无回收、单罐回收和分罐回收三种闭合工况。必须给出绝对分子分母、置信区间和重复次数，不能用“比零提高”或挑选不同热输入的相对值。

### 6.6 耐久和故障率验证

1000 h试验按低温循环、额定稳态、负载阶跃和停机冻融分段，记录净功率、每节电压、氢耗、绝缘、电导率、压降和泄漏。衰减定义固定为同温度同功率同气体条件下初始与终止净功率之比；试验中途更换膜电极、泵或控制器必须作为失效而非“维护后继续累计”。

低温故障率采用每次启动/每个运行小时的需求次数作分母，预先定义可恢复报警、降额和危险停机；95%置信区间采用二项或泊松方法。目标3%只能在足够样本量后讨论，少量演示启动不能证明。寿命与故障统计需同一硬件BOM版本。

## 7 第四阶段：逐级选型与型号建议

以下型号分“已核实公开资料的候选”“工程类别候选”“定制件”。候选不是采购承诺，所有与氢气、−30℃、高海拔、认证和寿命有关的字段必须取得供应商书面数据。

| 位号 | 部件 | 首选候选/型号 | 关键公开或设计参数 | 选用理由与缺口 |
|---|---|---|---|---|
| STK-101 | 液冷PEMFC电堆 | 定制70节×130 cm²；供应商待招标 | 156 A、45.5 V、约7.1 kW毛功率 | 现有项目型号未提供；必须提供−30℃极化和净功率保证 |
| CP-101 | 阴极空气压缩机 | Celeroton TurboCell CTi-1100 | 40—110 VDC；最大压比1.9@13 g/s；17 g/s；1.5 kW；−20—85℃ | 48 V匹配、无油气轴承；项目−30℃超出目录，需低温版/预热确认 |
| CP-102 | 空气替代候选 | CTi-1101 | 压比1.6、25 g/s；同系列 | 高原流量余量较大，压力裕量较小，需堆压降确认 |
| P-301 | 主冷却泵 | 24 V CAN智能液泵，供应商定制30 L/min、80 kPa | ≤200 W目标；−30℃黏度曲线 | 项目原泵表为大功率系统，不直接指定旧型号 |
| P-401 | 床液泵 | 同系列定制15 L/min、60 kPa | 低温防冻液、空转/堵转反馈 | 必须与主泵分回路，避免一泵故障拖全机 |
| TV-301/302 | 电子节温器/三通阀 | 电控三通球阀或比例阀，DN15/20定制 | 0—100%位置反馈、−40—85℃、失效旁通 | 原图的“电子节温器”未给型号；按流量与低温验证选型 |
| HX-201 | 氢气伴热换热器 | 定制双壁316L微型换热器 | 150 W额定、250 W峰值、气侧≤3 kPa | 原需求表体积180×130×80 mm但热量过大口径属大系统，按本项目重算 |
| HX-301 | 主/次隔离换热器 | 定制316L双壁板式/壳管式 | 5 kW、低电导率侧、15 L/min、液侧压损≤25 kPa | 材料洁净和氢-液隔离优先，需离子析出证明 |
| MH-201—204 | 固态床 | TiFe0.85Mn0.05工业粉末，批次定制 | 目标1.0 wt%@55℃/25→1 bar；活化后3.28 kg/L表观密度 | 论文支持但不是供应合同，须按批次PCT验收 |
| GH-205/206 | 启动气瓶 | 35 MPa Type III/IV氢瓶，单瓶6.8 L，具体型号由持证供应商 | 设计可用约0.15 kg/瓶 | 不能用普通CNG/呼吸器瓶；需PRD、温度/冲击和低温阀总成 |
| PT-101/201 | 氢压力传感器 | WIKA MH-3-HY（量程按压力层级订购） | 316L/2.4711，氢兼容，350 bar tank或减压后约20 bar应用 | 官方页面说明MH-3已被MH-4替代，实际采购先核新型号 |
| PT-301 | 冷却液压力 | 工业0—200 kPaA低温隔膜变送器，型号待冻结 | 介质兼容、电导率不污染 | 不用氢传感器代替水路传感器 |
| FT-101 | 空气质量流量 | Sensirion SFM3003-300-CL候选 | −30—300 SLPM、低压降、I²C | 额定454 NL/min超过300 SLPM，需并联/大量程或更换，不能直接使用单只 |
| FT-201 | 氢流量 | 热式/科里奥利氢专用0—150 NL/min | 湿氢/压力、低温和吹扫适配 | Sensirion公开300 SLPM器件是空气/氧等候选，不自动适用于氢 |
| CVM-101 | 70节单体巡检 | Analog Devices LTC6806，多片级联 | 36通道、±5 V、144节、6.75 ms全量快采样 | 官方明确面向燃料电池监测；70节需2—3片并核隔离 |
| BMS-101 | 电池管理 | TI BQ76952参考，配外部AFE/接触器 | 3—16串监控保护 | 20s2p电池需要两片或更高压BMS，BQ76952不能单片覆盖20串 |
| BAT-101 | 启动/缓冲电池 | Toshiba SCiB 20Ah-HP | 2.3 V、20 Ah、25℃10 s约1900 W、−30℃可用宣传能力 | 20s2p，46 V/40 Ah；官方低温能力需整包和120 s实测 |
| IMD-101 | 绝缘监测 | Bender IR155/ISO系列，待按48 V系统确认 | DC绝缘监测、CAN/继电器输出 | 型号按系统是否浮地、泄漏电容与法规确定 |
| H2-DET-101/102 | 氢浓度检测 | H2scan HY-ALERTA 5000系列或同等级低温型 | 固定点低浓度报警，型号按量程 | 公开页面要求登录手册；必须取得−30℃响应和防护等级数据 |
| K-PDU | 主接触器 | Gigavac GV200系列候选 | 48 V、≥200 A连续/短时能力由型号确认 | 125 A母线留热降额和短路开断余量 |
| FCU-101 | 控制器 | STM32G474RE自研ECU或工业控制器 | 170 MHz级MCU、CAN-FD/ADC/PWM资源 | 软件安全、看门狗、时间戳、HIL需团队实施 |
| U-CAN | CAN收发器 | TI TCAN1042HGV-Q1候选 | 车规高速CAN、总线保护 | 低温和隔离方案配线束验证 |
| U-ADC | 模拟测量 | AD7124-8候选 | 8通道24位低噪声ADC | PT100/压力通道需前端防浪涌和隔离，不直接替代安全链 |
| DI-301 | 去离子支路 | 可更换燃料电池低电导率滤芯定制 | 0.3—1 L/min、旁路 | 按5 μS/cm目标、离子析出试验定芯材 |
| PTC-101 | 电堆小循环加热 | 3 kW低压PTC液体加热器 | 24/48 V、流量互锁、限温 | 只能有液流时通电，配置独立熔断/接触器 |
| R-301 | 散热器 | 定制10 kW高原水冷散热器，双风机 | 4000 m、+20℃、10 kW、总工作风量≥2500 m³/h | 不能以自由风量目录值替代静压曲线 |
| XV-H2-201 | 氢切断 | 氢兼容常闭电磁/气动切断阀，型号待供应商 | 压力按层级、−40—85℃、失电关断 | 安全阀与比例阀分功能，不用比例阀承担急停 |
| PRD-205 | 高压泄压 | 瓶厂配套PRD，型号与瓶证绑定 | 定压泄放、导管接安全排放区 | 不由控制器软件决定是否泄压 |
| J-H2 | 氢快插接口 | Parker/Swagelok氢兼容认证系列，最终型号待确认 | 防错、盲插、带阀快插 | 快插不能作为承重件，必须独立支架 |

选型顺序必须是：部件功能和边界 → 供应商性能地图 → 低温/高原/氢兼容证明 → 安全认证 → 接口/重量/维护 → 最后冻结具体料号。当前只有Celeroton、WIKA、ADI、TI、Toshiba、Sensirion等公开资料可作为候选；电堆、床体、换热器、泵、散热器、阀和高压瓶仍应走定制询价及样件验收，报告没有虚构一个“已购买型号”。

## 8 质量、体积、成本和工程可行性估算

| 模块 | 质量范围 | 体积/包络初值 | 备注 |
|---|---:|---:|---|
| 四固态床（含60 kg合金） | 300—360 kg | 4×0.07 m³ | 单罐75—90 kg估算 |
| 两启动气瓶及框架 | 35—50 kg | 0.08—0.12 m³ | 不含整机防护箱 |
| 70节堆、压缩机、阳极气液 | 25—45 kg | 0.08—0.15 m³ | 供应商差异很大 |
| 双液路、散热器、泵阀 | 35—55 kg | 0.15—0.25 m³ | 10 kW高原散热器为主 |
| 电池、DC/DC、PDU、控制 | 55—80 kg | 0.10—0.16 m³ | 20s2p电芯本体21.8 kg |
| 外壳、隔板、线束、管路、吊架 | 50—70 kg | 0.20—0.35 m³ | 防护和检修空间不可省 |
| **整机初估** | **430—660 kg** | **约0.8—1.2 m³** | 推车/撬装；不宣称单人/双人搬运 |

成本仅用于立项预算而非报价：定制堆/控制与功率件15—35万元；四床合金、承压结构与换热件15—35万元；氢瓶、阀件、泵、空压机与传感器10—25万元；结构、线束、样机加工和低温台架20—50万元。首台工程样机粗估60—145万元人民币；材料与认证批次会造成大幅变化。不要用网上零售件价格替代氢能系统安全件成本。

能量密度按可用2.46 kg氢、按LHV33.33 kWh/kg和系统5 kW连续约5.29 h估算，燃料化学能约82 kWh，整机有效电能约26.5 kWh，按430—660 kg为40—62 Wh/kg。若只统计5 kW母座和0.3 kg启动瓶，会得到虚假的高能量密度；本表明确包含长时固态储氢床。

## 9 专利、论文与研发边界

### 9.1 已核实公开专利

1. **US 12,385,676，Metal hydride heat exchanger and method of use，FFI IONIX IP，公开/授权页面日期2025-08-12。**公开摘要和权利要求包含高长径比储氢容器、长管/盘管、工作流体管和外部换热腔；权利要求还点到Ti-Mn合金、80—120 mesh、过滤及夹套。其前代US 11,566,853页面也已读取。项目不能简单复制“长径比盘管＋夹套”作为独立专利方案，必须做权利要求对比和设计绕开。
2. **US 8,636,836，Finned heat exchangers for metal hydride storage systems（FPO检索结果）。**说明翅片/换热器用于金属氢化物储氢系统的先有技术。作为B1方案的背景专利，不代表所有翅片结构都被覆盖；应由专利代理人逐项检索。
3. **US 8,778,063，Coiled and microchannel heat exchangers for metal hydride storage systems（FPO检索结果）。**说明盘管、微通道和固液换热已被公开，强化床不能只把形状名称写成创新点。
4. **US 12,347,900，Cold start control method and system for fuel cell vehicles，Hyundai/Kia，公开页面日期2025-07-01。**其权利要求使用停机冷却液温度、估计达到参考温度的时间和需求时间比值修正目标加热值。项目可借鉴“剩余时间比”思想，但要采用自己的四床能量状态、气瓶剩余氢、母管压力和负载约束，并做FTO检索。
5. **US 2025/0201877 A1，Cold start control method of fuel cell stack and cold start system of fuel cell stack，Hyundai/Kia，公开页面日期2025-06-19。**其权利要求涉及冷启动、空气切断阀和堆电压恢复判据。项目保留单体电压恢复，但采用双源供氢、分床余热和独立硬线安全链，不能据此宣称自由可专利。

专利页面来自FPO公开文本检索，不是法律意见；FPO/搜索结果可能遗漏同族、权利要求状态和中国专利。定型前应检索CNIPA、WIPO Patentscope、Google Patents和USPTO，并让专利代理人针对“分批床体调度＋低温气瓶桥接＋闭式低电导率双液路＋资格流量切换”做新颖性/FTO分析。

### 9.2 论文、厂商和检索记录

| 编号 | 来源 | 用途 |
|---|---|---|
| L1 | Barale et al., TiFe0.85Mn0.05 alloy produced at industrial level, arXiv:2202.12753，全文检索2026-09-09 | 工业密度、1.0 wt%、55℃/25→1 bar、250循环、活化/污染风险 |
| L2 | Dematteis et al., Fundamental hydrogen storage properties..., arXiv:2012.00354，全文检索2026-09-09 | Ti/Mn替代、PCT平台、解吸焓熵、t90 |
| L3 | Dreistadt et al., Effective Activation Method..., arXiv:2205.09429，题录摘要检索2026-09-09 | 50/90℃活化时间差 |
| L4 | Luo & Jiao, Cold start of proton exchange membrane fuel cell，DOI 10.1016/j.pecs.2017.10.003 | 低温结冰/含水控制综述 |
| L5 | Lototskyy et al., Use of metal hydrides in fuel cell applications，DOI 10.1016/j.pnsc.2017.01.008 | 金属氢化物—燃料电池耦合综述 |
| L6 | Experimental study on rapid cold start-up performance of PEMFC system，DOI 10.1016/j.ijhydene.2023.01.364，Crossref记录 | 冷启动试验方向 |
| L7 | Cold start performance analysis ... assisted heating，DOI 10.1016/j.csite.2025.106178，Crossref记录 | 辅助加热比较方向 |
| L8 | Numerical analysis and structural optimization ...，DOI 10.1016/j.renene.2026.126270，Crossref记录 | 结构优化方向 |
| L9 | 3D numerical study ... branching type fins，DOI 10.1016/j.icheatmasstransfer.2025.110301，Crossref记录 | 分支翅片方向 |
| L10 | Numerical modeling ... spiral fins，DOI 10.1016/j.icheatmasstransfer.2025.109972，Crossref记录 | 螺旋翅片方向 |
| M1 | Celeroton CTi-110x官方页面/数据表 | 空压机公开候选：48/80/96 V、40—110 V、1.6—1.9压比、8—18 g/s系列；CTi-1100 1.5 kW/17 g/s且环境下限−20℃ |
| M2 | WIKA MH-3-HY官方页面 | 316L/2.4711、350 bar储氢或减压后压力传感器、氢兼容/E1/EC79信息 |
| M3 | Toshiba SCiB 20Ah-HP官方页面 | 2.3 V、20 Ah、1900 W/10 s@25℃、545 g、低温可用宣传边界 |
| M4 | Analog Devices LTC6806官方页面 | 36通道燃料电池巡检、±5 V、144节级联、6.75 ms快采样 |
| M5 | Sensirion SFM3003-300-CL官方页面 | −30—300 SLPM空气/氧等低压降流量计；不足以覆盖本项目454 NL/min单支路 |

原始网页、PDF、题录、请求状态和检索日期存于`research/web`；状态码或页面受限的来源在对应JSON中保留，没有静默替换为二手结论。

## 10 设计冻结前的参数、风险和下一步

### 10.1 必须向供应商索取

1. 电堆70节或可替代节数的完整极化/效率/产热/水管理地图，包含−30℃、高海拔、寿命末期和允许阳阴极压差；
2. TiFe-Mn每批PCT、动力学、粒径、表观密度、循环容量和90℃活化记录；
3. 压力容器计算书、材料兼容性、焊接/NDT、疲劳、PRD和氢渗透数据；
4. 空压机在−30℃、5000 m、0—12 g/s的压比—效率—功率和喘振图，CTi-1100需明确低温适用性；
5. 泵在−30℃实际防冻液的流量—扬程—功耗—启动电流曲线；
6. 换热器在低电导率液侧的离子析出、压降、热阻、耐压和泄漏检测方法；
7. 电池整包的−30℃可用功率、SOC窗口、热管理和120 s脉冲能量；
8. 所有阀的低温动作时间、失电状态、密封寿命、氢兼容和认证；
9. 传感器的量程、误差、漂移、冗余、响应、故障诊断和安装姿态；
10. 所有压力层级的安全阀/PRD排放路径和安装法规。

### 10.2 设计风险排序

**R1 氢床净容量/重量。** 1 wt%工业材料使四床达到约240 kg合金；优先做5—10 kg同结构样件和质量闭合。若应用必须≤100 kg，应改为气氢轻量模块或显著缩短满功率续航。

**R2 主液路热量不够。** 当前堆HHV反应热9.08 kW、床吸热1.80 kW，理论上可供热，但散热器、泵和换热温差均会消耗余量。没有泵和换热器实曲线前，不能承诺所有四床按80分钟接管。

**R3 −30℃自主冷启动。** 电池能量300 Wh只是9 kW×120 s的一阶数值，不含峰值、低温容量、变换损耗和风机惯性。必须做冷浸启动和FC自主功率分账。

**R4 选型温度缺口。** CTi-1100目录下限−20℃，项目−30℃；SFM3003量程300 SLPM，额定空气约454 NL/min；WIKA MH-3页面提示已被MH-4取代。这些不应在BOM中标为已冻结型号。

**R5 专利自由实施。** 高长径比管、翅片、盘管、堆冷启动时间修正均有公开专利；项目创新必须落在可验证的组合、接口、调度和指标闭合，且需要FTO。

### 10.3 90天执行顺序

**第1—2周：** 冻结海拔、负载谱、整机质量上限、5 kW连续与5小时之间的优先级；向电堆、空压机、泵、床材料和高压瓶发出同一接口数据包。

**第3—4周：** 5—10 kg床样件B0/B1/B2/B3并行；建立PCT和恒压放氢台架；完成电堆单体电压采样板和氢气安全链HIL。

**第5—8周：** 完成Fluent局部模型网格无关性和实测泵/换热器降阶参数；四床调度与120 s启动Python模型转OpenModelica/Simscape；完成DC/DC和电池低温功率测试。

**第9—12周：** 在环境舱做−30℃冷启动、气瓶—首床切换、0.5—5 kW负载阶跃和故障注入；根据数据重算BOM、压力等级、散热器和续航；再冻结首台撬装图纸。

当前不建议先加工四只60 kg储氢床。先用一只5—10 kg特征样件证明传热、粉末过滤、压力、温度均匀性和安全泄放，再放大到四罐；否则即使结构能装下合金，容量、换热和低温启动也无法同时证明。

## 11 交付物说明

本目录中的`01_系统详细设计报告.md`是详细正文；`tools/calculate.py`是计算源；`calculations/parameters.json`与`bed_model.json`是运行结果；两张PNG是辅助图；`research/local_extracts`是项目资料提取；`research/web`是论文、专利、厂商与检索记录。`PROJECT_CONTEXT.md`、新系统架构图及现有正式图纸保持原位置，不被本次设计文件覆盖。

### 参考文件路径

* 项目要求：`PROJECT_CONTEXT.md`、`challenge_week1_requirements.md`
* 主架构图：`新系统架构图.pdf`
* 参数校核：`高寒地区氢能移动电源_物理要求与参数验证汇总.md`
* 现有控制/电气：`deliverables/启动与正常工作控制流程模拟.md`、`LOW_VOLTAGE_ARCHITECTURE_V21_HANDOFF.md`
* 材料调查：`tifemn_physical_parameter_comparison.md`、`storage_cooling_solution_survey.md`
* 现有图纸：`deliverables/图纸.pdf`、`deliverables/5kW_high_cold_hydrogen_prototype_wiring_package.pdf`

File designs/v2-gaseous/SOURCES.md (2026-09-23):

# 参数来源与公开范围

## 参考采购平台

H-WCS-SP-7K产品页面在2026-09-21本地调研中记录为119节、200 cm²活性面积、80 A、约90 V、7.1 kW、242×200×550 mm、约28 kg。公开运行环境5～35℃；测试65℃、常压、阴阳极100%RH。

来源：[Fuel Cell Store H-WCS-SP-7K产品页](https://www.fuelcellstore.com/fuel-cell-stacks/h-wcs-sp-7k-water-cooled-7kw-pemfc-stack)。

2026-09-23模型沿用该日期的参数摘记，不表示重新确认供货或厂家保证4000 m、−30℃和本模型工作点。原页面还存在名义/峰值/额定口径及取整问题，必须索取当前正式数据表。此次不公开第三方网页全文和完整手册。

## 物性与数值工具

- [CoolProp Hydrogen](https://coolprop.org/fluid_properties/fluids/Hydrogen.html)：气体密度和温压使用实际安装的`Hydrogen`后端，版本保存在JSON。
- [CoolProp不可压缩流体文档](https://coolprop.org/fluid_properties/Incompressibles.html)：低温物性示例使用`INCOMP::MEG-50%`。50%为质量分数，不能直接等同于50%体积分数或某电堆获准冷却液。
- [SciPy root](https://docs.scipy.org/doc/scipy/reference/generated/scipy.optimize.root.html)、[least_squares](https://docs.scipy.org/doc/scipy/reference/generated/scipy.optimize.least_squares.html)、[solve_ivp](https://docs.scipy.org/doc/scipy/reference/generated/scipy.integrate.solve_ivp.html)：方程与瞬态求解工具；软件使用不代表物理模型经过实验验证。

## 工程假设

单节0.75/0.70 V、97%新鲜氢利用率、散热器迎风UA系数、风机效率、液路阻力、85%冷却液热分配、低温风机功率预算、伴热与保温参数均为模型假设。不是采购保证值。

高压瓶参考充装状态为15℃、35 MPa绝压；温变压力用于容量/状态研究，不能代替认证瓶的充装温度补偿和最高允许压力规定。尺寸表中明确区分供应商历史尺寸、计算值和占位预算。

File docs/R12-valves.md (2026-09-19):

# R12阀门及接口逐项连接清单

核对日期：2026-09-15。模型：`新设计\FreeCAD_详细装配\R12_紧凑分层与圆弧管路\3D燃料电池模型.FCStd`。

本版替换原有按电气支线统计的清单。读取FreeCAD文件内的对象名称、中文标签和独立Shape，并按R12管路端点表逐个追踪接口；阀体及63根内部管路的Shape数据已与R12交付参考模型逐项比对一致。此处记录模型已有连接，不代表重新完成干涉或密封校核。

## 1. 数量与模型实际拆分程度

本次逐项核对 **14个阀门、阀块或止回汇流相关模型对象，52个外部流体接口**。其中13个对象有阀类电气支线，另有不在该电气清单中的`HydrogenHeader`六路止回合流对象。每一个外部接口单独列一行，没有将供液、回液、气口或放散口合并。

**14是模型对象数，不是内部独立阀芯总数。** 当前模型把隔离、比例、止回等功能合在单个Shape内，没有分别建立每只内部阀及其进出口。能够逐个确认的外部接口全部列在下文；内部未建出的端口不能写成已经存在。

| 序号 | FreeCAD对象名 | 模型中文标签 | 外部流体接口数 | 电气支线标识 |
|---:|---|---|---:|---|
| 1 | `AirValve` | 空气截止与计量（XV-101） | 2 | XV101 |
| 2 | `BackPressure` | 阴极背压阀（BPV-101） | 2 | BPV101 |
| 3 | `Mix` | 低压缓冲计量切断（H2-201） | 3 | XV201 |
| 4 | `TV1` | 余热分配三通（TV-301） | 3 | TV301 |
| 5 | `TV2` | 散热旁通三通（TV-302） | 4 | TV302 |
| 6 | `BedSupply` | 床路选择阀组（BS-401） | 6 | BS401 |
| 7 | `BedReturn` | 床路回流阀组（BR-401） | 7 | BR401 |
| 8 | `HydrogenHeader` | 六路止回合流（HM-201） | 7 | 无独立电气支线 |
| 9 | `Train201` | 床支路隔离比例止回（XV/PCV/CV-201） | 2 | PCV201 |
| 10 | `Train202` | 床支路隔离比例止回（XV/PCV/CV-202） | 2 | PCV202 |
| 11 | `Train203` | 床支路隔离比例止回（XV/PCV/CV-203） | 2 | PCV203 |
| 12 | `Train204` | 床支路隔离比例止回（XV/PCV/CV-204） | 2 | PCV204 |
| 13 | `Reg205` | 双级减压·切断·比例·止回（REG-205） | 5 | PCV205 |
| 14 | `Reg206` | 双级减压·切断·比例·止回（REG-206） | 5 | PCV206 |

## 2. 每个阀体的逐端口连接

下表“连接到”表示管路几何连接关系，不把端点表中的a/b顺序强行当作工况流向。接口代码保留模型原值；管外径由建模管路外半径计算，单位mm，不是DN或螺纹规格。

### 2.1 空气截止与计量（XV-101） — `AirValve`

| 本体接口 | 介质 | 管路编号 | 管外径/mm | 连接到的设备 | 对端接口 |
|---|---|---|---:|---|---|
| `AV.I` | 空气 | `Pipe003` | 46 | 板翅空气调温器（HX-101）（`AirHX`） | `AH.O` |
| `AV.O` | 空气 | `Pipe004` | 46 | 70节电堆·端板拉杆（STK-101）（`Stack`） | `STK.AI` |

### 2.2 阴极背压阀（BPV-101） — `BackPressure`

| 本体接口 | 介质 | 管路编号 | 管外径/mm | 连接到的设备 | 对端接口 |
|---|---|---|---:|---|---|
| `BP.I` | 空气 | `Pipe005` | 46 | 70节电堆·端板拉杆（STK-101）（`Stack`） | `STK.AO` |
| `BP.O` | 空气 | `Pipe059` | 46 | 阴极排气接口（`AIR_OUT`） | `AIR_OUT.PORT` |

### 2.3 低压缓冲计量切断（H2-201） — `Mix`

| 本体接口 | 介质 | 管路编号 | 管外径/mm | 连接到的设备 | 对端接口 |
|---|---|---|---:|---|---|
| `MX.I` | 氢气/含氢排放 | `Pipe007` | 12 | 双壁氢伴热器（HX-201）（`H2HX`） | `HH.O` |
| `MX.R` | 氢气/含氢排放 | `Pipe011` | 12 | 湿氢循环泵（HCP-201）（`Recirc`） | `RC.O` |
| `MX.O` | 氢气/含氢排放 | `Pipe008` | 12 | 70节电堆·端板拉杆（STK-101）（`Stack`） | `STK.HI` |

该对象接氢气伴热器、湿氢循环泵和电堆阳极入口，属于低压氢气计量切断部分，不能按英文对象名Mix翻译成冷却液混水阀。

### 2.4 余热分配三通（TV-301） — `TV1`

| 本体接口 | 介质 | 管路编号 | 管外径/mm | 连接到的设备 | 对端接口 |
|---|---|---|---:|---|---|
| `TV1.I` | 主冷却液 | `Pipe014` | 26 | 主液热供分配（CH-301）（`HotHeader`） | `HOT.TV1` |
| `TV1.HX` | 主冷却液 | `Pipe015` | 26 | 双壁液液隔离（HX-301）（`Isolation`） | `HX.MI` |
| `TV1.BY` | 主冷却液 | `Pipe034` | 26 | 散热旁通三通（TV-302）（`TV2`） | `TV2.SHORT` |

### 2.5 散热旁通三通（TV-302） — `TV2`

| 本体接口 | 介质 | 管路编号 | 管外径/mm | 连接到的设备 | 对端接口 |
|---|---|---|---:|---|---|
| `TV2.I` | 主冷却液 | `Pipe016` | 26 | 双壁液液隔离（HX-301）（`Isolation`） | `HX.MO` |
| `TV2.RAD` | 主冷却液 | `Pipe017` | 26 | 侧水室与框架·前后通风（R-301）（`Radiator`） | `RAD.I` |
| `TV2.BY` | 主冷却液 | `Pipe020` | 26 | 主液回流汇集（CR-301）（`ReturnHeader`） | `RET.TV2` |
| `TV2.SHORT` | 主冷却液 | `Pipe034` | 26 | 余热分配三通（TV-301）（`TV1`） | `TV1.BY` |

模型有I、RAD、BY、SHORT四个外部接口，必须分别保留。虽然标签称“三通”，几何拓扑实际列有4口，其中SHORT接TV1旁通。内部是否为合流口或附加短接腔未单独建出，不能在接口表中删掉SHORT来凑成三口。

### 2.6 床路选择阀组（BS-401） — `BedSupply`

| 本体接口 | 介质 | 管路编号 | 管外径/mm | 连接到的设备 | 对端接口 |
|---|---|---|---:|---|---|
| `BS.IN` | 储氢次冷却液 | `Pipe031` | 22 | 双壁液液隔离（HX-301）（`Isolation`） | `HX.BO` |
| `BS.201` | 储氢次冷却液 | `Pipe037` | 22 | 固态储氢模块（MH201）（`MH201`） | `MH201.S` |
| `BS.202` | 储氢次冷却液 | `Pipe041` | 22 | 固态储氢模块（MH202）（`MH202`） | `MH202.S` |
| `BS.203` | 储氢次冷却液 | `Pipe045` | 22 | 固态储氢模块（MH203）（`MH203`） | `MH203.S` |
| `BS.204` | 储氢次冷却液 | `Pipe049` | 22 | 固态储氢模块（MH204）（`MH204`） | `MH204.S` |
| `BS.REG` | 储氢次冷却液 | `Pipe055` | 22 | 双级减压·切断·比例·止回（REG-205）（`Reg205`） | `REG205.S` |

### 2.7 床路回流阀组（BR-401） — `BedReturn`

| 本体接口 | 介质 | 管路编号 | 管外径/mm | 连接到的设备 | 对端接口 |
|---|---|---|---:|---|---|
| `BR.OUT` | 储氢次冷却液 | `Pipe032` | 22 | 床泵·15升/分钟（P-401）（`BedPump`） | `BPU.I` |
| `BR.201` | 储氢次冷却液 | `Pipe038` | 22 | 固态储氢模块（MH201）（`MH201`） | `MH201.R` |
| `BR.202` | 储氢次冷却液 | `Pipe042` | 22 | 固态储氢模块（MH202）（`MH202`） | `MH202.R` |
| `BR.203` | 储氢次冷却液 | `Pipe046` | 22 | 固态储氢模块（MH203）（`MH203`） | `MH203.R` |
| `BR.204` | 储氢次冷却液 | `Pipe050` | 22 | 固态储氢模块（MH204）（`MH204`） | `MH204.R` |
| `BR.TK` | 储氢次冷却液 | `Pipe033` | 22 | 独立次路膨胀罐（TK-401）（`TKbed`） | `TKB.FILL` |
| `BR.REG` | 储氢次冷却液 | `Pipe057` | 22 | 双级减压·切断·比例·止回（REG-206）（`Reg206`） | `REG206.R` |

### 2.8 六路止回合流（HM-201） — `HydrogenHeader`

| 本体接口 | 介质 | 管路编号 | 管外径/mm | 连接到的设备 | 对端接口 |
|---|---|---|---:|---|---|
| `HM.201` | 氢气/含氢排放 | `Pipe036` | 12 | 床支路隔离比例止回（XV/PCV/CV-201）（`Train201`） | `V201.O` |
| `HM.202` | 氢气/含氢排放 | `Pipe040` | 12 | 床支路隔离比例止回（XV/PCV/CV-202）（`Train202`） | `V202.O` |
| `HM.203` | 氢气/含氢排放 | `Pipe044` | 12 | 床支路隔离比例止回（XV/PCV/CV-203）（`Train203`） | `V203.O` |
| `HM.204` | 氢气/含氢排放 | `Pipe048` | 12 | 床支路隔离比例止回（XV/PCV/CV-204）（`Train204`） | `V204.O` |
| `HM.205` | 氢气/含氢排放 | `Pipe052` | 12 | 双级减压·切断·比例·止回（REG-205）（`Reg205`） | `REG205.O` |
| `HM.206` | 氢气/含氢排放 | `Pipe054` | 12 | 双级减压·切断·比例·止回（REG-206）（`Reg206`） | `REG206.O` |
| `HM.OUT` | 氢气/含氢排放 | `Pipe006` | 12 | 双壁氢伴热器（HX-201）（`H2HX`） | `HH.I` |

### 2.9 床支路隔离比例止回（XV/PCV/CV-201） — `Train201`

| 本体接口 | 介质 | 管路编号 | 管外径/mm | 连接到的设备 | 对端接口 |
|---|---|---|---:|---|---|
| `V201.I` | 氢气/含氢排放 | `Pipe035` | 12 | 固态储氢模块（MH201）（`MH201`） | `MH201.H` |
| `V201.O` | 氢气/含氢排放 | `Pipe036` | 12 | 六路止回合流（HM-201）（`HydrogenHeader`） | `HM.201` |

### 2.10 床支路隔离比例止回（XV/PCV/CV-202） — `Train202`

| 本体接口 | 介质 | 管路编号 | 管外径/mm | 连接到的设备 | 对端接口 |
|---|---|---|---:|---|---|
| `V202.I` | 氢气/含氢排放 | `Pipe039` | 12 | 固态储氢模块（MH202）（`MH202`） | `MH202.H` |
| `V202.O` | 氢气/含氢排放 | `Pipe040` | 12 | 六路止回合流（HM-201）（`HydrogenHeader`） | `HM.202` |

### 2.11 床支路隔离比例止回（XV/PCV/CV-203） — `Train203`

| 本体接口 | 介质 | 管路编号 | 管外径/mm | 连接到的设备 | 对端接口 |
|---|---|---|---:|---|---|
| `V203.I` | 氢气/含氢排放 | `Pipe043` | 12 | 固态储氢模块（MH203）（`MH203`） | `MH203.H` |
| `V203.O` | 氢气/含氢排放 | `Pipe044` | 12 | 六路止回合流（HM-201）（`HydrogenHeader`） | `HM.203` |

### 2.12 床支路隔离比例止回（XV/PCV/CV-204） — `Train204`

| 本体接口 | 介质 | 管路编号 | 管外径/mm | 连接到的设备 | 对端接口 |
|---|---|---|---:|---|---|
| `V204.I` | 氢气/含氢排放 | `Pipe047` | 12 | 固态储氢模块（MH204）（`MH204`） | `MH204.H` |
| `V204.O` | 氢气/含氢排放 | `Pipe048` | 12 | 六路止回合流（HM-201）（`HydrogenHeader`） | `HM.204` |

### 2.13 双级减压·切断·比例·止回（REG-205） — `Reg205`

| 本体接口 | 介质 | 管路编号 | 管外径/mm | 连接到的设备 | 对端接口 |
|---|---|---|---:|---|---|
| `REG205.I` | 氢气/含氢排放 | `Pipe051` | 12 | 气态储氢瓶（GH205，35兆帕，概念容量22.174升）（`GH205`） | `GH205.H` |
| `REG205.O` | 氢气/含氢排放 | `Pipe052` | 12 | 六路止回合流（HM-201）（`HydrogenHeader`） | `HM.205` |
| `REG205.PRD` | 氢气/含氢排放 | `Pipe061` | 12 | 气瓶205安全放散接口（`VENT205`） | `VENT205.PORT` |
| `REG205.S` | 储氢次冷却液 | `Pipe055` | 22 | 床路选择阀组（BS-401）（`BedSupply`） | `BS.REG` |
| `REG205.R` | 储氢次冷却液 | `Pipe056` | 22 | 双级减压·切断·比例·止回（REG-206）（`Reg206`） | `REG206.S` |

I、O为氢气支路接口；PRD为安全放散接口；S、R为伴热次液路接口。伴热供回液不等同于氢气入口/出口，五个接口均独立列出。

### 2.14 双级减压·切断·比例·止回（REG-206） — `Reg206`

| 本体接口 | 介质 | 管路编号 | 管外径/mm | 连接到的设备 | 对端接口 |
|---|---|---|---:|---|---|
| `REG206.I` | 氢气/含氢排放 | `Pipe053` | 12 | 气态储氢瓶（GH206，35兆帕，概念容量22.174升）（`GH206`） | `GH206.H` |
| `REG206.O` | 氢气/含氢排放 | `Pipe054` | 12 | 六路止回合流（HM-201）（`HydrogenHeader`） | `HM.206` |
| `REG206.PRD` | 氢气/含氢排放 | `Pipe062` | 12 | 气瓶206安全放散接口（`VENT206`） | `VENT206.PORT` |
| `REG206.S` | 储氢次冷却液 | `Pipe056` | 22 | 双级减压·切断·比例·止回（REG-205）（`Reg205`） | `REG205.R` |
| `REG206.R` | 储氢次冷却液 | `Pipe057` | 22 | 床路回流阀组（BR-401）（`BedReturn`） | `BR.REG` |

I、O为氢气支路接口；PRD为安全放散接口；S、R为伴热次液路接口。伴热供回液不等同于氢气入口/出口，五个接口均独立列出。

## 3. 组合对象内部的阀门功能逐项展开

下表逐只列出标签明确表示的阀门功能，不把隔离、比例和止回统称为一只阀。由于内部没有独立端口和连接管段，表中的对象外端口只用于定位整个支路，不代表各内部阀共用一个接口；内部阀的顺序和相互连接仍缺模型数据。

| 阀门功能名称 | 所在模型对象 | 对象入口定位 | 对象出口定位 | 内部接口状态 |
|---|---|---|---|---|
| 隔离切断阀 XV-201 | `Train201` | `V201.I` | `V201.O` | 未独立建模；无可追踪的内部端口 |
| 比例调节阀 PCV-201 | `Train201` | `V201.I` | `V201.O` | 未独立建模；无可追踪的内部端口 |
| 止回阀 CV-201 | `Train201` | `V201.I` | `V201.O` | 未独立建模；无可追踪的内部端口 |
| 隔离切断阀 XV-202 | `Train202` | `V202.I` | `V202.O` | 未独立建模；无可追踪的内部端口 |
| 比例调节阀 PCV-202 | `Train202` | `V202.I` | `V202.O` | 未独立建模；无可追踪的内部端口 |
| 止回阀 CV-202 | `Train202` | `V202.I` | `V202.O` | 未独立建模；无可追踪的内部端口 |
| 隔离切断阀 XV-203 | `Train203` | `V203.I` | `V203.O` | 未独立建模；无可追踪的内部端口 |
| 比例调节阀 PCV-203 | `Train203` | `V203.I` | `V203.O` | 未独立建模；无可追踪的内部端口 |
| 止回阀 CV-203 | `Train203` | `V203.I` | `V203.O` | 未独立建模；无可追踪的内部端口 |
| 隔离切断阀 XV-204 | `Train204` | `V204.I` | `V204.O` | 未独立建模；无可追踪的内部端口 |
| 比例调节阀 PCV-204 | `Train204` | `V204.I` | `V204.O` | 未独立建模；无可追踪的内部端口 |
| 止回阀 CV-204 | `Train204` | `V204.I` | `V204.O` | 未独立建模；无可追踪的内部端口 |
| REG-205 第一级减压阀 | `Reg205` | `REG205.I` | `REG205.O` | 未独立建模；名称按对象标签展开 |
| REG-205 第二级减压阀 | `Reg205` | `REG205.I` | `REG205.O` | 未独立建模；名称按对象标签展开 |
| REG-205 切断阀 | `Reg205` | `REG205.I` | `REG205.O` | 未独立建模；名称按对象标签展开 |
| REG-205 比例调节阀 | `Reg205` | `REG205.I` | `REG205.O` | 未独立建模；名称按对象标签展开 |
| REG-205 止回阀 | `Reg205` | `REG205.I` | `REG205.O` | 未独立建模；名称按对象标签展开 |
| REG-206 第一级减压阀 | `Reg206` | `REG206.I` | `REG206.O` | 未独立建模；名称按对象标签展开 |
| REG-206 第二级减压阀 | `Reg206` | `REG206.I` | `REG206.O` | 未独立建模；名称按对象标签展开 |
| REG-206 切断阀 | `Reg206` | `REG206.I` | `REG206.O` | 未独立建模；名称按对象标签展开 |
| REG-206 比例调节阀 | `Reg206` | `REG206.I` | `REG206.O` | 未独立建模；名称按对象标签展开 |
| REG-206 止回阀 | `Reg206` | `REG206.I` | `REG206.O` | 未独立建模；名称按对象标签展开 |

上述4个床支路标签表示12项阀门功能，2个减压站标签表示10项阀门功能，共22项；这不是22只已分别建出的阀门实体，也不能与14个对象数直接相加。

床路选择阀组BS-401、回流阀组BR-401的每个外部口已单独列出，但内部阀芯数量未定义；不能简单按外接口个数认定阀门个数。HM-201标签为“六路止回合流”，下列六路各自保留：

| 合流支路 | 上游端口 | 管路 | 汇流接口 | 止回功能位置说明 |
|---|---|---|---|---|
| 201 | `V201.O` | `Pipe036` | `HM.201` | 汇流件标签表示止回，但未建独立阀芯；不能确认是否另加于上游止回功能 |
| 202 | `V202.O` | `Pipe040` | `HM.202` | 汇流件标签表示止回，但未建独立阀芯；不能确认是否另加于上游止回功能 |
| 203 | `V203.O` | `Pipe044` | `HM.203` | 汇流件标签表示止回，但未建独立阀芯；不能确认是否另加于上游止回功能 |
| 204 | `V204.O` | `Pipe048` | `HM.204` | 汇流件标签表示止回，但未建独立阀芯；不能确认是否另加于上游止回功能 |
| 205 | `REG205.O` | `Pipe052` | `HM.205` | 汇流件标签表示止回，但未建独立阀芯；不能确认是否另加于上游止回功能 |
| 206 | `REG206.O` | `Pipe054` | `HM.206` | 汇流件标签表示止回，但未建独立阀芯；不能确认是否另加于上游止回功能 |

## 4. 与排氢、放散及气瓶有关的接口逐项补充

阳极吹扫排放、阴极空气排放和气瓶安全放散是不同路径，不允许合并成一个“排氢阀”。

| 起点接口 | 管路编号 | 对端接口 | 模型意义 |
|---|---|---|---|
| `STK.AO` | `Pipe005` | `BP.I` | 电堆阴极出口接背压阀入口 |
| `BP.O` | `Pipe059` | `AIR_OUT.PORT` | 阴极背压阀出口接阴极排气接口 |
| `SEP.DRAIN` | `Pipe060` | `PURGE.PORT` | 阳极分水器排放口接阳极吹扫排放接口；未找到独立排氢阀对象 |
| `REG205.PRD` | `Pipe061` | `VENT205.PORT` | 205减压站PRD接205安全放散接口 |
| `REG206.PRD` | `Pipe062` | `VENT206.PORT` | 206减压站PRD接206安全放散接口 |
| `GH205.H` | `Pipe051` | `REG205.I` | 205气瓶出口接205减压站入口 |
| `GH206.H` | `Pipe053` | `REG206.I` | 206气瓶出口接206减压站入口 |

气瓶出口对象GH205、GH206未单独拆出瓶阀端口；PRD有外部接口和管路，但未独立列为可电控排氢阀。原统计把BPV101归为排氢执行器的说法撤回。

## 5. 电气接插件逐件定位

流体接口与电气接口分别统计。下面13条电气支线各自列出设备端、线束、网关端；多芯插头中的针脚是功能分配，没有供应商针号，不能据此填写原PPT的P1/P2/P3针号。

| 设备对象 | 设备端接插件 | 线束 | 网关端接插件 | 已记录芯线功能 |
|---|---|---|---|---|
| `AirValve` | `Connector_XV101` | `Cable_XV101` | `HubPort_XV101` | 6 pins: 24V,0V, command,feedback,return,shield |
| `BackPressure` | `Connector_BPV101` | `Cable_BPV101` | `HubPort_BPV101` | 6 pins: 24V,0V, command,feedback,return,shield |
| `Mix` | `Connector_XV201` | `Cable_XV201` | `HubPort_XV201` | 6 pins: 24V,0V, command,feedback,return,shield |
| `TV1` | `Connector_TV301` | `Cable_TV301` | `HubPort_TV301` | 6 pins: 24V,0V, command,feedback,return,shield |
| `TV2` | `Connector_TV302` | `Cable_TV302` | `HubPort_TV302` | 6 pins: 24V,0V, command,feedback,return,shield |
| `BedSupply` | `Connector_BS401` | `Cable_BS401` | `HubPort_BS401` | 6 pins: 24V,0V, command,feedback,return,shield |
| `BedReturn` | `Connector_BR401` | `Cable_BR401` | `HubPort_BR401` | 6 pins: 24V,0V, command,feedback,return,shield |
| `Train201` | `Connector_PCV201` | `Cable_PCV201` | `HubPort_PCV201` | 8 pins: cutoff pair, proportional pair,feedback pair,PE,spare |
| `Train202` | `Connector_PCV202` | `Cable_PCV202` | `HubPort_PCV202` | 8 pins: cutoff pair, proportional pair,feedback pair,PE,spare |
| `Train203` | `Connector_PCV203` | `Cable_PCV203` | `HubPort_PCV203` | 8 pins: cutoff pair, proportional pair,feedback pair,PE,spare |
| `Train204` | `Connector_PCV204` | `Cable_PCV204` | `HubPort_PCV204` | 8 pins: cutoff pair, proportional pair,feedback pair,PE,spare |
| `Reg205` | `Connector_PCV205` | `Cable_PCV205` | `HubPort_PCV205` | 8 pins: cutoff, proportional and feedback |
| `Reg206` | `Connector_PCV206` | `Cable_PCV206` | `HubPort_PCV206` | 8 pins: cutoff, proportional and feedback |

各网关端接插件属于JB-101分布式I/O网关。一个阀组插头并不证明该阀组只有一个内部执行器；例如PCV201～204的记录分别包含切断线对和比例线对。

## 6. 本次纠正及尚未拆出的结构

- `Mix / XV201`：低压氢气计量切断，不是主冷却液混水阀。
- `TV1 / TV301`：主液余热分配三通，连接主液热供汇管、隔离换热器主侧和TV2短接口。
- `TV2 / TV302`：主液散热旁通对象，不能标为储氢次液路节温器；四个已建外口逐一保留。
- `BackPressure / BPV101`：阴极空气背压阀，不是阳极排氢阀。
- `HydrogenHeader / HM201`：上一版电气支线统计遗漏了此止回合流对象，本版已逐路展开。
- 当前模型未分别建出组合阀内部进出口、独立阳极排氢阀和独立气瓶瓶阀，无法从模型可靠给出全部单阀总数。要得到逐只阀门采购清单，需要先把这些内部阀和接口拆成独立对象；本次没有修改三维模型。

## 7. 全部内部管路端点索引

为便于继续沿上下游查找，下面保留全部63根内部管路的两端。每根管路一行。

| 管路编号 | A端设备 | A端接口 | B端设备 | B端接口 | 介质 |
|---|---|---|---|---|---|
| `Pipe001` | 外界进气滤清器·双腔壳体（AF-101） | `AF.O` | 独立轴向进风过渡接管（CP-101） | `CP.I` | 空气 |
| `Pipe002` | 独立切向出风接管（CP-101） | `CP.O` | 板翅空气调温器（HX-101） | `AH.I` | 空气 |
| `Pipe003` | 板翅空气调温器（HX-101） | `AH.O` | 空气截止与计量（XV-101） | `AV.I` | 空气 |
| `Pipe004` | 空气截止与计量（XV-101） | `AV.O` | 70节电堆·端板拉杆（STK-101） | `STK.AI` | 空气 |
| `Pipe005` | 70节电堆·端板拉杆（STK-101） | `STK.AO` | 阴极背压阀（BPV-101） | `BP.I` | 空气 |
| `Pipe006` | 六路止回合流（HM-201） | `HM.OUT` | 双壁氢伴热器（HX-201） | `HH.I` | 氢气/含氢排放 |
| `Pipe007` | 双壁氢伴热器（HX-201） | `HH.O` | 低压缓冲计量切断（H2-201） | `MX.I` | 氢气/含氢排放 |
| `Pipe008` | 低压缓冲计量切断（H2-201） | `MX.O` | 70节电堆·端板拉杆（STK-101） | `STK.HI` | 氢气/含氢排放 |
| `Pipe009` | 70节电堆·端板拉杆（STK-101） | `STK.HO` | 伴热阳极分水器（SEP-201） | `SEP.I` | 氢气/含氢排放 |
| `Pipe010` | 伴热阳极分水器（SEP-201） | `SEP.O` | 湿氢循环泵（HCP-201） | `RC.I` | 氢气/含氢排放 |
| `Pipe011` | 湿氢循环泵（HCP-201） | `RC.O` | 低压缓冲计量切断（H2-201） | `MX.R` | 氢气/含氢排放 |
| `Pipe012` | 主泵·30升/分钟（P-301） | `MP.O` | 70节电堆·端板拉杆（STK-101） | `STK.CI` | 主冷却液 |
| `Pipe013` | 70节电堆·端板拉杆（STK-101） | `STK.CO` | 主液热供分配（CH-301） | `HOT.IN` | 主冷却液 |
| `Pipe014` | 主液热供分配（CH-301） | `HOT.TV1` | 余热分配三通（TV-301） | `TV1.I` | 主冷却液 |
| `Pipe015` | 余热分配三通（TV-301） | `TV1.HX` | 双壁液液隔离（HX-301） | `HX.MI` | 主冷却液 |
| `Pipe016` | 双壁液液隔离（HX-301） | `HX.MO` | 散热旁通三通（TV-302） | `TV2.I` | 主冷却液 |
| `Pipe017` | 散热旁通三通（TV-302） | `TV2.RAD` | 侧水室与框架·前后通风（R-301） | `RAD.I` | 主冷却液 |
| `Pipe018` | 侧水室与框架·前后通风（R-301） | `RAD.O` | 独立主路膨胀罐（TK-301） | `TKM.RET` | 主冷却液 |
| `Pipe019` | 独立主路膨胀罐（TK-301） | `TKM.FILL` | 主液回流汇集（CR-301） | `RET.TK` | 主冷却液 |
| `Pipe020` | 散热旁通三通（TV-302） | `TV2.BY` | 主液回流汇集（CR-301） | `RET.TV2` | 主冷却液 |
| `Pipe021` | 主液回流汇集（CR-301） | `RET.MP` | 主泵·30升/分钟（P-301） | `MP.I` | 主冷却液 |
| `Pipe022` | 主液热供分配（CH-301） | `HOT.AH` | 板翅空气调温器（HX-101） | `AH.F` | 主冷却液 |
| `Pipe023` | 板翅空气调温器（HX-101） | `AH.E` | 主液回流汇集（CR-301） | `RET.AH` | 主冷却液 |
| `Pipe024` | 主液热供分配（CH-301） | `HOT.HH` | 双壁氢伴热器（HX-201） | `HH.B` | 主冷却液 |
| `Pipe025` | 双壁氢伴热器（HX-201） | `HH.A` | 主液回流汇集（CR-301） | `RET.HH` | 主冷却液 |
| `Pipe026` | 主液热供分配（CH-301） | `HOT.SEP` | 伴热阳极分水器（SEP-201） | `SEP.D` | 主冷却液 |
| `Pipe027` | 伴热阳极分水器（SEP-201） | `SEP.C` | 主液回流汇集（CR-301） | `RET.SEP` | 主冷却液 |
| `Pipe028` | 主液热供分配（CH-301） | `HOT.DI` | 去离子旁路（DI-301） | `DI.I` | 主冷却液 |
| `Pipe029` | 去离子旁路（DI-301） | `DI.O` | 主液回流汇集（CR-301） | `RET.DI` | 主冷却液 |
| `Pipe030` | 床泵·15升/分钟（P-401） | `BPU.O` | 双壁液液隔离（HX-301） | `HX.BI` | 储氢次冷却液 |
| `Pipe031` | 双壁液液隔离（HX-301） | `HX.BO` | 床路选择阀组（BS-401） | `BS.IN` | 储氢次冷却液 |
| `Pipe032` | 床路回流阀组（BR-401） | `BR.OUT` | 床泵·15升/分钟（P-401） | `BPU.I` | 储氢次冷却液 |
| `Pipe033` | 独立次路膨胀罐（TK-401） | `TKB.FILL` | 床路回流阀组（BR-401） | `BR.TK` | 储氢次冷却液 |
| `Pipe034` | 余热分配三通（TV-301） | `TV1.BY` | 散热旁通三通（TV-302） | `TV2.SHORT` | 主冷却液 |
| `Pipe035` | 固态储氢模块（MH201） | `MH201.H` | 床支路隔离比例止回（XV/PCV/CV-201） | `V201.I` | 氢气/含氢排放 |
| `Pipe036` | 床支路隔离比例止回（XV/PCV/CV-201） | `V201.O` | 六路止回合流（HM-201） | `HM.201` | 氢气/含氢排放 |
| `Pipe037` | 床路选择阀组（BS-401） | `BS.201` | 固态储氢模块（MH201） | `MH201.S` | 储氢次冷却液 |
| `Pipe038` | 固态储氢模块（MH201） | `MH201.R` | 床路回流阀组（BR-401） | `BR.201` | 储氢次冷却液 |
| `Pipe039` | 固态储氢模块（MH202） | `MH202.H` | 床支路隔离比例止回（XV/PCV/CV-202） | `V202.I` | 氢气/含氢排放 |
| `Pipe040` | 床支路隔离比例止回（XV/PCV/CV-202） | `V202.O` | 六路止回合流（HM-201） | `HM.202` | 氢气/含氢排放 |
| `Pipe041` | 床路选择阀组（BS-401） | `BS.202` | 固态储氢模块（MH202） | `MH202.S` | 储氢次冷却液 |
| `Pipe042` | 固态储氢模块（MH202） | `MH202.R` | 床路回流阀组（BR-401） | `BR.202` | 储氢次冷却液 |
| `Pipe043` | 固态储氢模块（MH203） | `MH203.H` | 床支路隔离比例止回（XV/PCV/CV-203） | `V203.I` | 氢气/含氢排放 |
| `Pipe044` | 床支路隔离比例止回（XV/PCV/CV-203） | `V203.O` | 六路止回合流（HM-201） | `HM.203` | 氢气/含氢排放 |
| `Pipe045` | 床路选择阀组（BS-401） | `BS.203` | 固态储氢模块（MH203） | `MH203.S` | 储氢次冷却液 |
| `Pipe046` | 固态储氢模块（MH203） | `MH203.R` | 床路回流阀组（BR-401） | `BR.203` | 储氢次冷却液 |
| `Pipe047` | 固态储氢模块（MH204） | `MH204.H` | 床支路隔离比例止回（XV/PCV/CV-204） | `V204.I` | 氢气/含氢排放 |
| `Pipe048` | 床支路隔离比例止回（XV/PCV/CV-204） | `V204.O` | 六路止回合流（HM-201） | `HM.204` | 氢气/含氢排放 |
| `Pipe049` | 床路选择阀组（BS-401） | `BS.204` | 固态储氢模块（MH204） | `MH204.S` | 储氢次冷却液 |
| `Pipe050` | 固态储氢模块（MH204） | `MH204.R` | 床路回流阀组（BR-401） | `BR.204` | 储氢次冷却液 |
| `Pipe051` | 气态储氢瓶（GH205，35兆帕，概念容量22.174升） | `GH205.H` | 双级减压·切断·比例·止回（REG-205） | `REG205.I` | 氢气/含氢排放 |
| `Pipe052` | 双级减压·切断·比例·止回（REG-205） | `REG205.O` | 六路止回合流（HM-201） | `HM.205` | 氢气/含氢排放 |
| `Pipe053` | 气态储氢瓶（GH206，35兆帕，概念容量22.174升） | `GH206.H` | 双级减压·切断·比例·止回（REG-206） | `REG206.I` | 氢气/含氢排放 |
| `Pipe054` | 双级减压·切断·比例·止回（REG-206） | `REG206.O` | 六路止回合流（HM-201） | `HM.206` | 氢气/含氢排放 |
| `Pipe055` | 床路选择阀组（BS-401） | `BS.REG` | 双级减压·切断·比例·止回（REG-205） | `REG205.S` | 储氢次冷却液 |
| `Pipe056` | 双级减压·切断·比例·止回（REG-205） | `REG205.R` | 双级减压·切断·比例·止回（REG-206） | `REG206.S` | 储氢次冷却液 |
| `Pipe057` | 双级减压·切断·比例·止回（REG-206） | `REG206.R` | 床路回流阀组（BR-401） | `BR.REG` | 储氢次冷却液 |
| `Pipe058` | 外界进气滤清器·双腔壳体（AF-101） | `AF.I` | 外界进气接口 | `AIR_IN.PORT` | 空气 |
| `Pipe059` | 阴极背压阀（BPV-101） | `BP.O` | 阴极排气接口 | `AIR_OUT.PORT` | 空气 |
| `Pipe060` | 伴热阳极分水器（SEP-201） | `SEP.DRAIN` | 阳极吹扫排放接口 | `PURGE.PORT` | 氢气/含氢排放 |
| `Pipe061` | 双级减压·切断·比例·止回（REG-205） | `REG205.PRD` | 气瓶205安全放散接口 | `VENT205.PORT` | 氢气/含氢排放 |
| `Pipe062` | 双级减压·切断·比例·止回（REG-206） | `REG206.PRD` | 气瓶206安全放散接口 | `VENT206.PORT` | 氢气/含氢排放 |
| `Pipe063` | 独立次路膨胀罐（TK-401） | `TKB.RET` | 储氢床回路加注接口 | `BED_FILL.PORT` | 储氢次冷却液 |

## 8. 核对来源

- 模型SHA-256：`57f0196c2182c30709bab60726b57c284196504f0ab9af68db21f34a101cb850`。
- 模型Document.xml：设备名称、中文标签、独立Shape及对象拆分情况。
- `work/compact_r12/routing_built.json`：逐端口所属对象、管路A/B端、介质与外径。
- `work/compact_r12/assembly_wired.json`：逐支线接插件与芯线功能。
- 与`work/compact_r12/r12_view.FCStd`一致性核对：77个阀/汇流对象及管路Shape全部一致。

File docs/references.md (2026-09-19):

# 来源与检索记录

检索日期：2026-09-09。联网来源只用于技术依据、型号核查和专利初筛；专利状态、权利要求范围、FTO和认证必须在冻结设计前由专业机构复核。

## 本地项目来源

`PROJECT_CONTEXT.md`：当前有效路线、55节初值、冷启动状态、风险与图纸要求。

`新系统架构图.pdf`：四固态床、双气瓶、两液路、氢/空气伴热、液-液换热器的主框架。

`challenge_week1_requirements.md`：题目硬指标与评分要求。

`高寒地区氢能移动电源_物理要求与参数验证汇总.md`：空气流量、换热器热负荷、母线电流、氢耗和质量冲突的核算。

`初步调研2.md`、`tifemn_physical_parameter_comparison.md`、`storage_cooling_solution_survey.md`：路线比较、TiFe-Mn参数、低温与材料文献线索。

`初步检测阈值与传感器清单.md`、`deliverables/启动与正常工作控制流程模拟.md`、`LOW_VOLTAGE_ARCHITECTURE_V21_HANDOFF.md`：传感器、状态机、低压电气和安全链。

`氢气换热器技术需求-V1.0.xlsx`、`水泵技术需求_V1.0(1).xlsx`：前期接口需求；因其部分数据为大功率系统，本次没有直接照搬。

## 论文与题录

1. Barale et al., “TiFe0.85Mn0.05 alloy produced at industrial level for a hydrogen storage plant”, arXiv:2202.12753, https://arxiv.org/abs/2202.12753。全文已保存research/web/barale_full.pdf。
2. Dematteis et al., “Fundamental hydrogen storage properties of TiFe-alloy with partial substitution of Fe and Mn”, arXiv:2012.00354, https://arxiv.org/abs/2012.00354。全文已保存research/web/dematteis_full.pdf。
3. Dreistadt et al., “An Effective Activation Method for Industrially Produced TiFeMn Powder for Hydrogen Storage”, arXiv:2205.09429, https://arxiv.org/abs/2205.09429。
4. Luo & Jiao, “Cold start of proton exchange membrane fuel cell”, DOI:10.1016/j.pecs.2017.10.003。
5. Lototskyy et al., “The use of metal hydrides in fuel cell applications”, DOI:10.1016/j.pnsc.2017.01.008。
6. “Experimental study on rapid cold start-up performance of PEMFC system”, DOI:10.1016/j.ijhydene.2023.01.364。
7. “Cold start performance analysis of PEMFC with different assisted heating strategies”, DOI:10.1016/j.csite.2025.106178。
8. “Numerical analysis and structural optimization of PEMFC cold-start performance”, DOI:10.1016/j.renene.2026.126270。
9. “3D numerical study of hydrogen storage in nano-enhanced metal hydride reactor with branching type fins”, DOI:10.1016/j.icheatmasstransfer.2025.110301。
10. “Numerical modeling study of hydrogen absorption process in metal hydride hydrogen storage reactors with spiral fins”, DOI:10.1016/j.icheatmasstransfer.2025.109972。

## 专利初筛

* US 12,385,676, “Metal hydride heat exchanger and method of use”, FFI IONIX IP, 页面日期2025-08-12，公开文本：https://www.freepatentsonline.com/12385676.html。
* US 11,566,853, “Metal hydride heat exchanger and method of use”, Xergy Inc.，公开文本：https://www.freepatentsonline.com/11566853.html。
* US 8,636,836, “Finned heat exchangers for metal hydride storage systems”，FPO检索结果。
* US 8,778,063, “Coiled and microchannel heat exchangers for metal hydride storage systems”，FPO检索结果。
* US 12,347,900, “Cold start control method and system for fuel cell vehicles”, Hyundai/Kia, 页面日期2025-07-01，公开文本：https://www.freepatentsonline.com/12347900.html。
* US 2025/0201877 A1, “Cold start control method of fuel cell stack and cold start system of fuel cell stack”, Hyundai/Kia, 页面日期2025-06-19，公开文本：https://www.freepatentsonline.com/y2025/0201877.html。

## 厂商页面与数据表

* Celeroton TurboCell CTi-110x：https://www.celeroton-turbocell.com/en/home/；数据表PDF已保存research/web/datasheet_cti.pdf。
* WIKA MH-3-HY：https://www.wika.com/en-en/mh_3_hy.WIKA。
* Toshiba SCiB 20Ah-HP：https://www.global.toshiba/ww/products-solutions/battery/scib/product-next/product/cell/combination.html。
* Analog Devices LTC6806：https://www.analog.com/en/products/ltc6806.html。
* TI BQ76952：https://www.ti.com/product/BQ76952。
* Sensirion SFM3003-300-CL：https://sensirion.com/products/catalog/SFM3003-300-CL。
* TI TCAN1042HGV-Q1：https://www.ti.com/product/TCAN1042HGV-Q1。
* AD7124-8：https://www.analog.com/en/products/ad7124-8.html。
* H2scan HY-ALERTA 5000 series：https://h2scan.com/products/hy-alerta-500/。

所有网页原文/JSON/状态码保存在`research/web`。检索失败、403、404或页面需要登录的记录保留原样，不能当作已核实的规格。

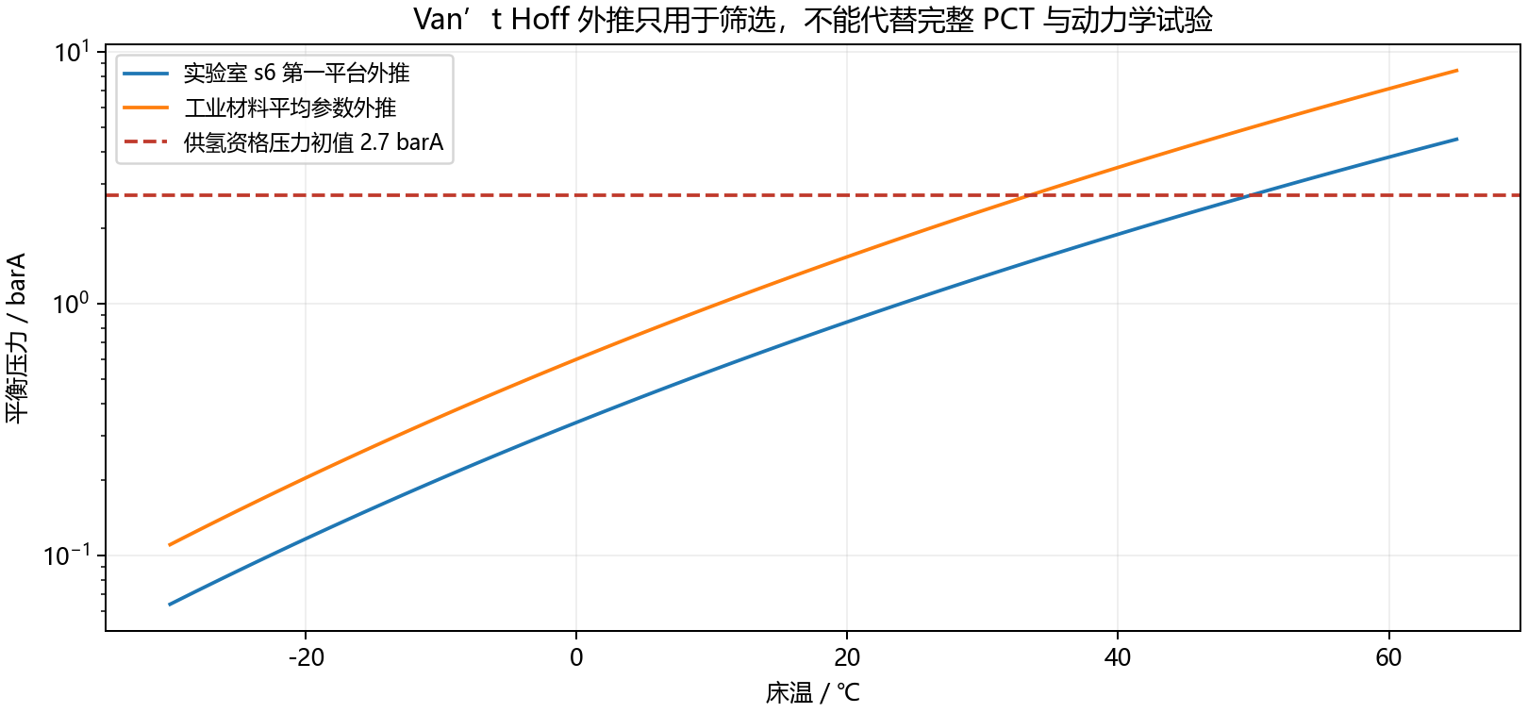
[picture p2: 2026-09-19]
calculations/pct_screen.png

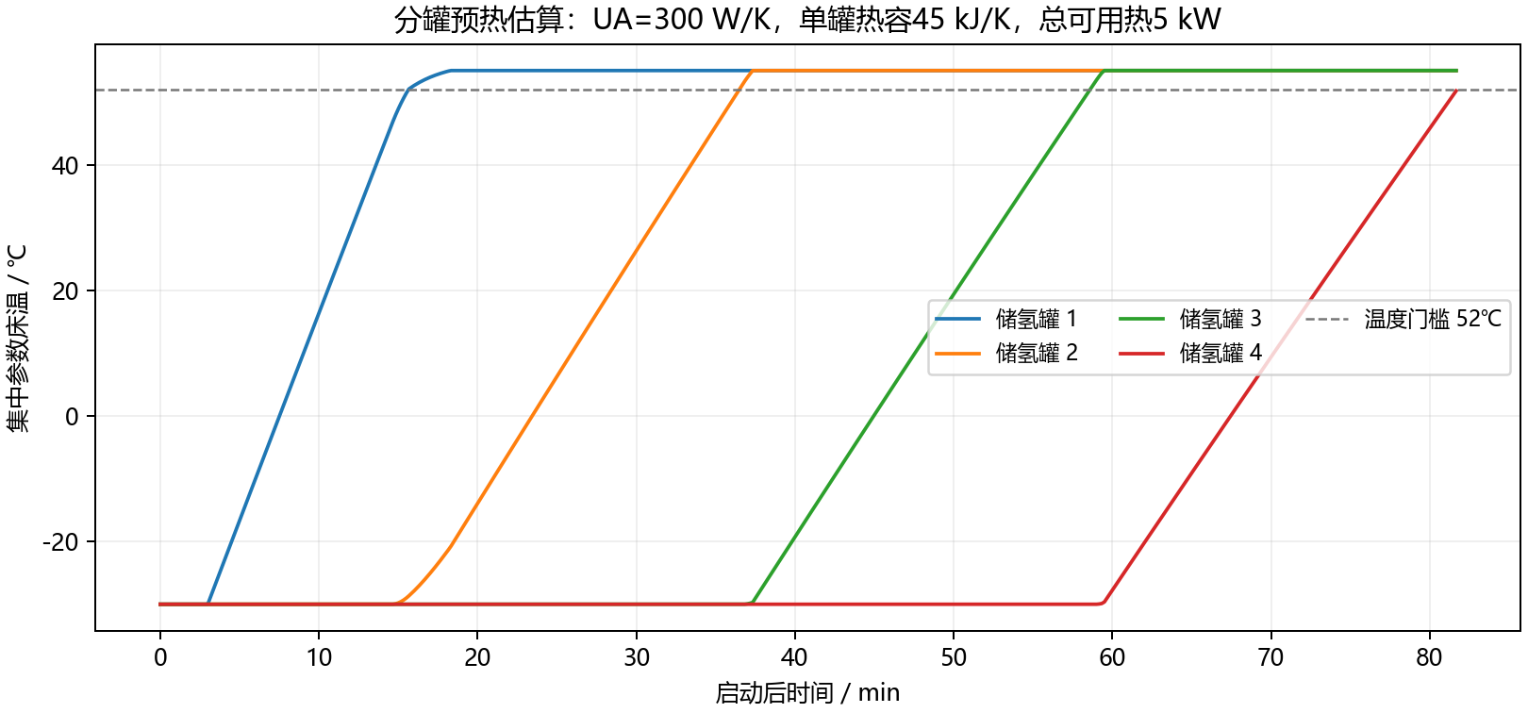
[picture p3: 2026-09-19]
calculations/bed_warmup.png

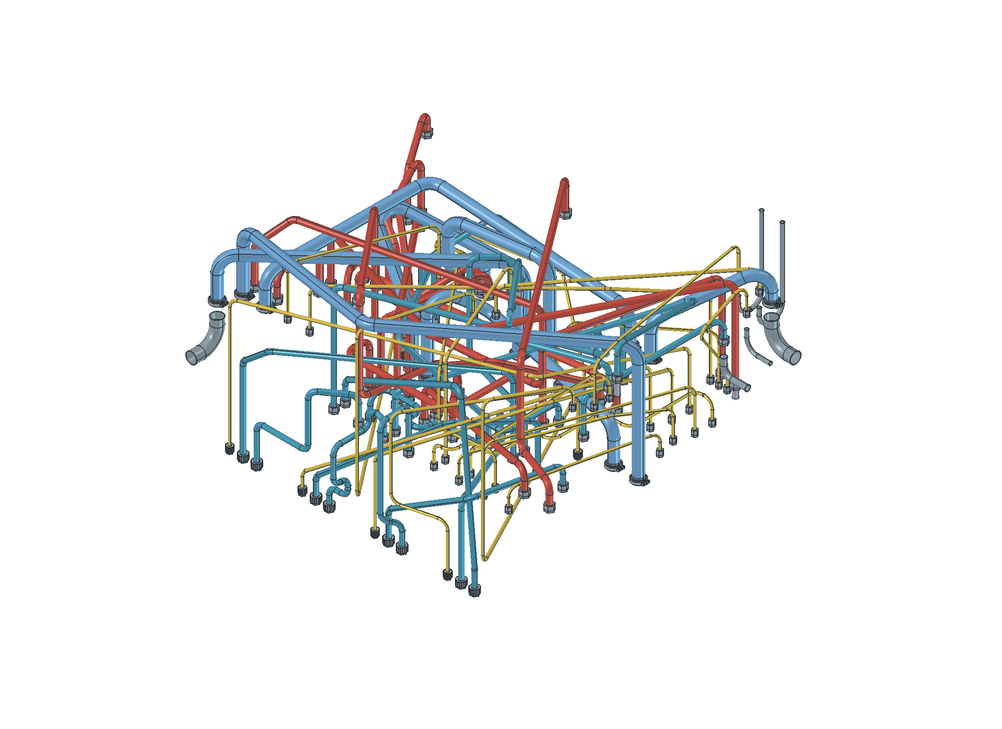
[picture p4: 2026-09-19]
models/R12/04_圆弧管路及可拆接口.png

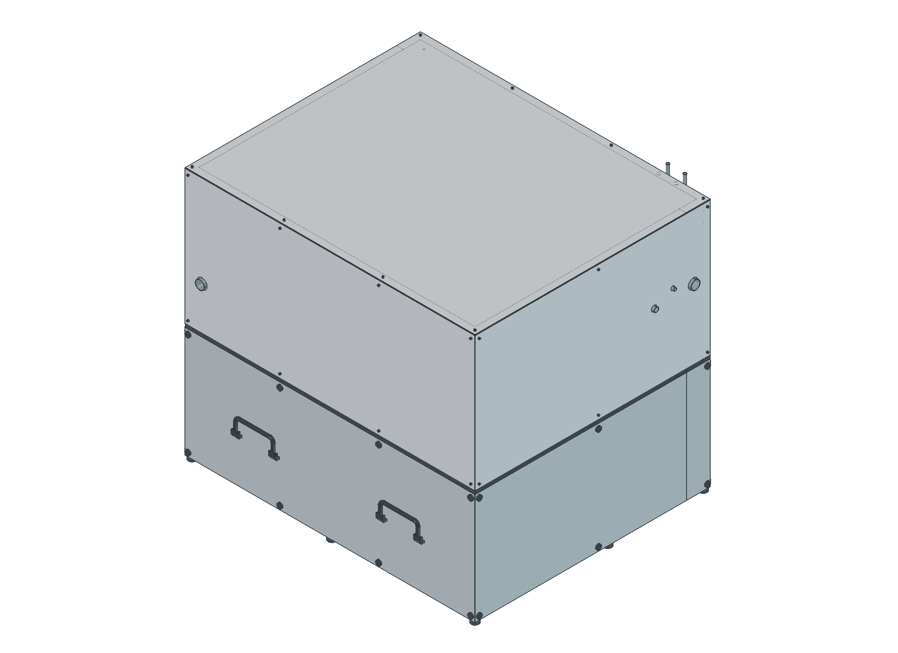
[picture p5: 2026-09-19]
models/R12/01_整机外壳.png

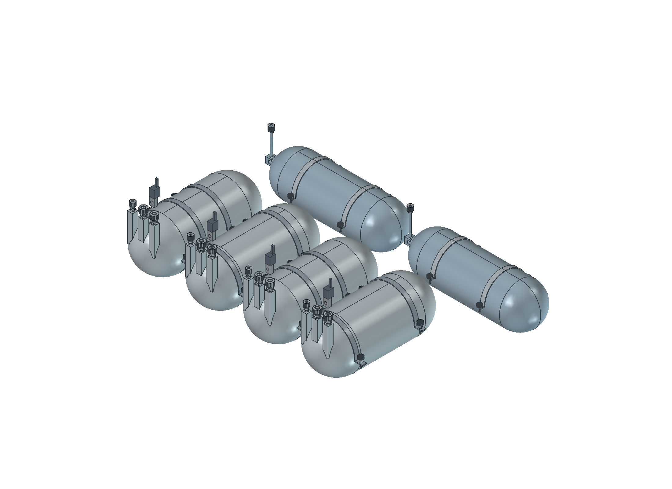
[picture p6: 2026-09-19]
models/R12/06_储氢模块断接细节.png

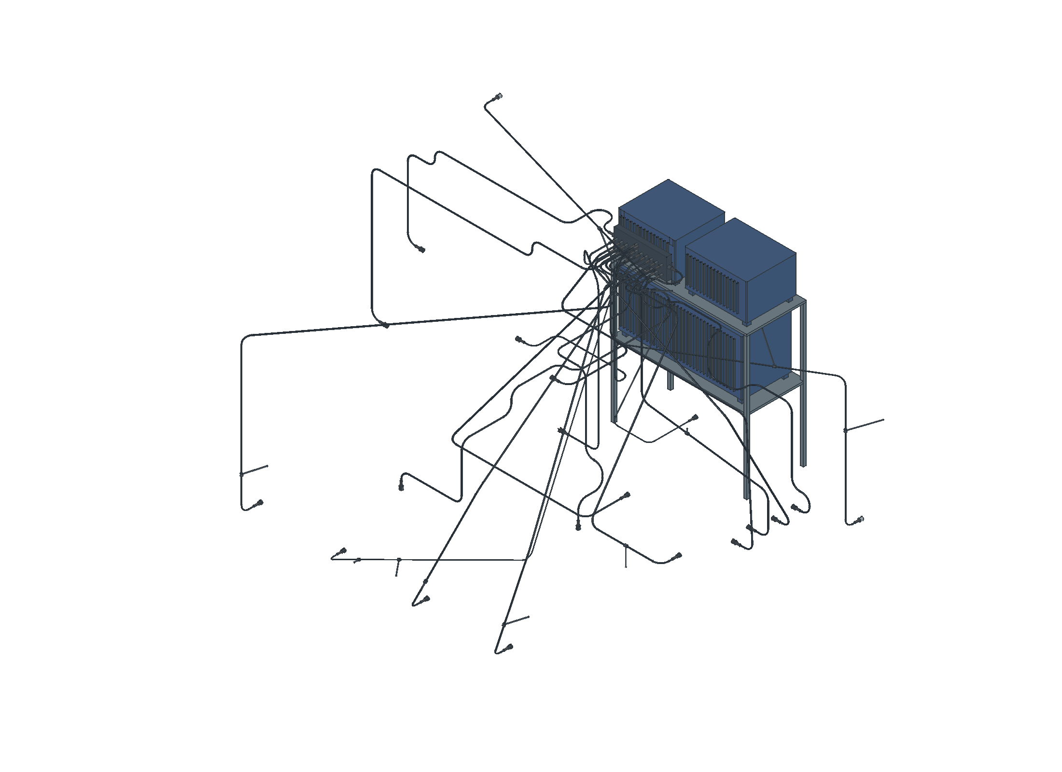
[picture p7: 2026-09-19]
models/R12/05_线束接插件与固定点.png

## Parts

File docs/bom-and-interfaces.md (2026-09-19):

# NDS-5K-R1 部件BOM与接口表

## 选型状态

`候选-公开` 表示型号和部分参数来自2026-09-09公开资料；`候选-工程` 表示产品类别和设计边界已定、具体料号待询价；`定制` 表示必须按本系统接口开发。任何候选在−30℃、高海拔、氢兼容、认证、寿命和失效状态未取得书面数据前都不能直接采购。

| 位号 | 数量 | 类别 | 首选型号/规格 | 关键接口 | 状态 |
|---|---:|---|---|---|---|
| STK-101 | 1 | 液冷PEMFC | 定制70节×130 cm²，156 A | H2低压、空气、液冷、约20-85 VDC | 定制 |
| CP-101 | 1 | 空气压缩机 | Celeroton TurboCell CTi-1100 | 40-110 VDC，CAN，17 g/s上限 | 候选-公开，−30℃缺口 |
| CP-102 | 1备选 | 空气压缩机 | CTi-1101 | 40-110 VDC，25 g/s，压比1.6 | 候选-公开，高原压比待核 |
| P-301 | 1 | 主冷却泵 | 24 V CAN智能泵，30 L/min@80 kPa | 24 V、CAN、流量/转速 | 候选-工程 |
| P-401 | 1 | 床液泵 | 24 V CAN智能泵，15 L/min@60 kPa | 24 V、CAN、流量/转速 | 候选-工程 |
| TV-301/302 | 2 | 三通阀 | DN15/20比例电控，带位置反馈 | 低电导率液/防冻液，−40—85℃ | 定制 |
| HX-101 | 1 | 空气调温器 | 板翅/微通道，0.6 kW、≤0.8 kPa | 空气DN40、液1-2 L/min | 定制 |
| HX-201 | 1 | 氢伴热换热器 | 双壁316L，150 W额定 | H2低压、液0.3-0.5 L/min | 定制 |
| HX-301 | 1 | 液-液隔离换热器 | 316L双壁，5 kW、15 L/min | 主路/次路独立、低离子析出 | 定制 |
| MH-201..204 | 4 | 固态储氢床 | TiFe0.85Mn0.05，60 kg/罐 | PCT承压、36温度点、供回液 | 定制 |
| GH-205/206 | 2 | 启动氢瓶 | 35 MPa、6.8 L、氢用Type III/IV | 瓶阀、PRD、一级减压 | 候选-工程 |
| PCV-201..206 | 6 | 配流阀 | 氢兼容比例阀，按压差定制 | 低压氢、0-100%反馈 | 定制 |
| SEP-201 | 1 | 阳极分水器 | 0.3-0.5 L气液腔，低点排水 | 湿氢、排水、伴热 | 定制 |
| HCP-201 | 1 | 氢循环泵 | 50-100 NL/min，5-15 kPa | 湿氢、CAN或PWM | 候选-工程 |
| PT-101/201 | 4 | 氢压力 | WIKA MH-3-HY/MH-4替代型号 | 量程按高压/减压/床压 | 候选-公开 |
| FT-101 | 1或并联 | 空气流量 | Sensirion SFM3003-300-CL或大量程型 | 0-300 SLPM单支路 | 候选-公开，量程不足 |
| FT-201 | 2 | 氢流量 | 0-150 NL/min氢专用质量流量 | 湿氢/压力/低温适配 | 候选-工程 |
| CVM-101 | 3 | 电堆巡检 | Analog Devices LTC6806 | 每片36通道，70节级联 | 候选-公开 |
| BAT-101 | 40芯 | 启动电池 | Toshiba SCiB 20Ah-HP，20s2p | 46 V、40 Ah | 候选-公开 |
| BMS-101 | 2 | BMS | TI BQ76952多片或高压替代 | 20串2并、接触器控制 | 候选-公开，单片不够 |
| IMD-101 | 1 | 绝缘监测 | Bender IR155/ISO系列 | 浮地48 V、CAN/继电器 | 候选-工程 |
| H2-DET-101/102 | 2 | 氢探测 | H2scan HY-ALERTA 5000系列 | 舱体高点、低温版 | 候选-公开资料不完整 |
| K-PDU | 2 | 主接触器 | Gigavac GV200系列 | ≥200 A、48 V、失电断开 | 候选-工程 |
| FCU-101 | 1 | 主控制器 | STM32G474RE自研ECU | CAN、ADC、PWM、看门狗 | 定制 |
| U-CAN | 4 | CAN收发器 | TI TCAN1042HGV-Q1 | 500 kbps/高速CAN | 候选-公开 |
| U-ADC | 2 | 精密ADC | AD7124-8 | 8通道24 bit | 候选-公开 |
| DI-301 | 1 | DI旁路 | 燃料电池低电导率滤芯 | 0.3-1 L/min | 候选-工程 |
| PTC-101 | 1 | 液体PTC | 3 kW、流量互锁 | 24/48 V，独立限温 | 候选-工程 |
| PTC-102 | 1 | 空气PTC | 0.5 kW，旁通 | 24/48 V，进气温控 | 候选-工程 |
| R-301 | 1 | 高原散热器 | 定制10 kW、双高静压风机 | 4000 m、+20℃、≥2500 m³/h工作风量 | 定制 |
| XV-H2 | 6 | 安全切断 | 氢兼容常闭阀 | 各压力层级、失电关断 | 候选-工程 |
| PRD-205 | 2 | 高压泄压 | 瓶厂配套PRD | 压力等级按瓶证 | 候选-工程 |
| J-H2/J-C | 若干 | 快插 | 氢/液分别认证快插 | 防错、盲插、带阀 | 候选-工程 |

## 关键接口冻结表

| 接口 | 初始值 | 设计审查条件 |
|---|---:|---|
| 低压氢母管 | 0.20 MPaA | P床大于母管+压损；阴阳极差压单独闭环 |
| 主冷却液 | 30 L/min，−40℃冻结保护目标 | 实际防冻液泵曲线及电导率 |
| 床回路 | 15 L/min，单罐可隔离 | 选择阀关闭憋压保护 |
| 48 V母线 | 45.6-50.4 V | 125 A连续、短时按负载谱；DC/DC输入20-85 V |
| CAN | 500 kbps，双端120 Ω | 支线长度、屏蔽、终端和故障状态 |
| 空气 | 9.78 g/s，4000 m−30℃约39.9 m³/h | 设备工作点和堆计量比确认 |
| 低电导率液 | ≤5 μS/cm目标，>10报警 | DI旁路、换热器离子析出试验 |

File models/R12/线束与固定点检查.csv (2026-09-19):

线束名称 | 编号 | 外径_mm | 弯曲半径_mm | 长度_mm | 起端直段_mm | 末端直段_mm | 中间结构线夹数
主干电源线束 | Cable_Backbone | 8.0 | 48.0 | 252.8 | 38.0 | 60.0 | 0
控制与传感线束 XV101 | Cable_XV101 | 5.5 | 33.0 | 1449.84 | 35.05 | 63.06 | 1
控制与传感线束 BPV101 | Cable_BPV101 | 3.5 | 21.0 | 1045.26 | 164.8 | 51.23 | 1
控制与传感线束 TE101 | Cable_TE101 | 5.0 | 30.0 | 1100.06 | 114.6 | 95.44 | 0
控制与传感线束 PCV202 | Cable_PCV202 | 5.5 | 33.0 | 1277.17 | 39.26 | 40.47 | 1
控制与传感线束 PCV203 | Cable_PCV203 | 5.5 | 33.0 | 1242.45 | 27.19 | 90.38 | 0
控制与传感线束 PCV204 | Cable_PCV204 | 5.5 | 33.0 | 1617.93 | 38.21 | 77.25 | 0
控制与传感线束 PCV206 | Cable_PCV206 | 5.5 | 33.0 | 1639.29 | 135.03 | 81.86 | 0
控制与传感线束 TT201 | Cable_TT201 | 5.0 | 30.0 | 2023.85 | 41.38 | 54.3 | 1
控制与传感线束 TT202 | Cable_TT202 | 4.0 | 24.0 | 2228.19 | 33.68 | 70.48 | 2
控制与传感线束 TT203 | Cable_TT203 | 5.0 | 30.0 | 1741.82 | 33.36 | 54.39 | 1
控制与传感线束 TT204 | Cable_TT204 | 5.0 | 30.0 | 1712.69 | 33.18 | 174.2 | 1
控制与传感线束 H2LOW | Cable_H2LOW | 5.0 | 30.0 | 1642.33 | 28.0 | 140.65 | 2
控制与传感线束 H2UP | Cable_H2UP | 5.0 | 30.0 | 1372.13 | 41.76 | 127.24 | 1
控制与传感线束 XV201 | Cable_XV201 | 4.5 | 27.0 | 1186.7 | 31.0 | 31.0 | 2
控制与传感线束 TV301 | Cable_TV301 | 5.5 | 33.0 | 1706.38 | 20.1 | 156.0 | 0
控制与传感线束 BR401 | Cable_BR401 | 5.5 | 33.0 | 1688.68 | 25.1 | 26.25 | 0
控制与传感线束 PCV201 | Cable_PCV201 | 5.5 | 33.0 | 1365.07 | 25.1 | 26.25 | 0
控制与传感线束 PCV205 | Cable_PCV205 | 5.5 | 33.0 | 785.37 | 25.1 | 106.25 | 0
控制与传感线束 TV302 | Cable_TV302 | 5.5 | 33.0 | 1341.89 | 20.1 | 25.0 | 0
控制与传感线束 BS401 | Cable_BS401 | 5.5 | 33.0 | 1323.69 | 57.0 | 30.0 | 0

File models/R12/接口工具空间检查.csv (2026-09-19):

接口编号 | 工具形式 | 管路安装阶段结果 | 螺母扳手或套筒方位_deg | 反力扳手方位_deg | 采用独立夹角 | 最少遮挡姿态中的零件
STK.AI | 双套筒 | 找到无碰撞包络姿态 | 240 |  | 否
STK.AO | 双套筒 | 找到无碰撞包络姿态 | 0 |  | 否
STK.HI | 双开口扳手 | 找到无碰撞包络姿态 | 60 | 240 | 否
STK.HO | 双开口扳手 | 找到无碰撞包络姿态 | 45 | 225 | 否
STK.CI | 双开口扳手 | 未找到无碰撞包络姿态 | 30 | 210 | 否 | 空气接头固定半体（STK.AI） [UnionBody_STK_AI]；空气接头开口卡箍（STK.AI） [UnionClamp_STK_AI]
STK.CO | 双开口扳手 | 未找到无碰撞包络姿态 | 90 | 270 | 否 | 空气接头管侧半体（STK.AO） [UnionTail_STK_AO]；空气接头开口卡箍（AIR_IN.PORT） [UnionClamp_AIR_IN_PORT]；卡箍紧固螺栓（AIR_IN.PORT） [UnionBolt_AIR_IN_PORT]；氢气管路035｜固态储氢模块（MH201）—XV/PCV/CV-201·床支路隔离比例止回 [Pipe035]
AF.I | 双套筒 | 找到无碰撞包络姿态 | 105 |  | 否
AF.O | 双套筒 | 找到无碰撞包络姿态 | 75 |  | 否
CP.I | 双套筒 | 找到无碰撞包络姿态 | 300 |  | 否
CP.O | 双套筒 | 找到无碰撞包络姿态 | 75 |  | 否
AH.I | 双套筒 | 找到无碰撞包络姿态 | 0 |  | 否
AH.O | 双套筒 | 找到无碰撞包络姿态 | 15 |  | 否
AH.F | 双开口扳手 | 未找到无碰撞包络姿态 | 105 | 285 | 否 | 卡箍六角螺母（AH.O） [UnionClampNut_AH_O]；主冷却液管路019｜TK-301·独立主路膨胀罐—CR-301·主液回流汇集 [Pipe019]；储氢床冷却液管路033｜TK-401·独立次路膨胀罐—BR-401·床路回流阀组 [Pipe033]
AH.E | 双开口扳手 | 未找到无碰撞包络姿态 | 120 | 300 | 否 | 主冷却液管路023｜HX-101·板翅空气调温器—CR-301·主液回流汇集 [Pipe023]；储氢床冷却液管路033｜TK-401·独立次路膨胀罐—BR-401·床路回流阀组 [Pipe033]
AV.I | 双套筒 | 未找到无碰撞包络姿态 | 105 |  | 否 | 独立次路膨胀罐（TK-401） [TKbed]
AV.O | 双套筒 | 找到无碰撞包络姿态 | 75 |  | 否
BP.I | 双套筒 | 未找到无碰撞包络姿态 | 15 |  | 否 | 钛酸锂启动电池组（BAT-101，20串2并） [Battery]
BP.O | 双套筒 | 找到无碰撞包络姿态 | 300 |  | 否
SEP.I | 双开口扳手 | 未找到无碰撞包络姿态 | 0 | 180 | 否 | 伴热阳极分水器（SEP-201） [Separator]；活接可旋转螺母（SEP.O） [UnionNut_SEP_O]；活接固定端与反力六角（SEP.D） [UnionBody_SEP_D]
SEP.O | 双开口扳手 | 未找到无碰撞包络姿态 | 255 | 75 | 否 | 分层安装托板_阴极背压阀（BPV-101） [Subtray_BackPressure]；氢气管路043｜固态储氢模块（MH203）—XV/PCV/CV-203·床支路隔离比例止回 [Pipe043]；氢气管路036｜XV/PCV/CV-201·床支路隔离比例止回—HM-201·六路止回合流 [Pipe036]
SEP.DRAIN | 双开口扳手 | 未找到无碰撞包络姿态 | 270 | 90 | 否 | 氢气管路044｜XV/PCV/CV-203·床支路隔离比例止回—HM-201·六路止回合流 [Pipe044]
SEP.D | 双开口扳手 | 找到无碰撞包络姿态 | 285 | 105 | 否
SEP.C | 双开口扳手 | 找到无碰撞包络姿态 | 0 | 180 | 否
RC.I | 双开口扳手 | 未找到无碰撞包络姿态 | 30 | 210 | 否 | 双级减压·切断·比例·止回（REG-205） [Reg205]；分层托板支柱_BackPressure [Standoff_BackPressure_0]
RC.O | 双开口扳手 | 未找到无碰撞包络姿态 | 150 | 330 | 否 | 独立次路膨胀罐（TK-401） [TKbed]；去离子旁路（DI-301） [DI]
HH.I | 双开口扳手 | 未找到无碰撞包络姿态 | 75 | 255 | 否 | 空气管路002｜CP-101·独立切向出风接管—HX-101·板翅空气调温器 [Pipe002]
HH.O | 双开口扳手 | 未找到无碰撞包络姿态 | 60 | 240 | 否 | 空气管路002｜CP-101·独立切向出风接管—HX-101·板翅空气调温器 [Pipe002]；主冷却液管路025｜HX-201·双壁氢伴热器—CR-301·主液回流汇集 [Pipe025]
HH.B | 双开口扳手 | 未找到无碰撞包络姿态 | 90 | 270 | 否 | 活接可旋转螺母（HH.A） [UnionNut_HH_A]；空气管路002｜CP-101·独立切向出风接管—HX-101·板翅空气调温器 [Pipe002]；空气管路003｜HX-101·板翅空气调温器—XV-101·空气截止与计量 [Pipe003]
HH.A | 双开口扳手 | 未找到无碰撞包络姿态 | 255 | 75 | 否 | 活接可旋转螺母（HH.B） [UnionNut_HH_B]；空气管路002｜CP-101·独立切向出风接管—HX-101·板翅空气调温器 [Pipe002]
MX.I | 双开口扳手 | 未找到无碰撞包络姿态 | 255 | 75 | 否 | 80根中空扁管·4排×20层（R-301） [RadiatorFlatTubes]；19层波纹翅片·0.18mm厚·10mm节距（R-301） [RadiatorCorrugatedFins]
MX.R | 双开口扳手 | 未找到无碰撞包络姿态 | 240 | 60 | 否 | 80根中空扁管·4排×20层（R-301） [RadiatorFlatTubes]；19层波纹翅片·0.18mm厚·10mm节距（R-301） [RadiatorCorrugatedFins]
MX.O | 双开口扳手 | 未找到无碰撞包络姿态 | 225 | 45 | 否 | 80根中空扁管·4排×20层（R-301） [RadiatorFlatTubes]；19层波纹翅片·0.18mm厚·10mm节距（R-301） [RadiatorCorrugatedFins]
MP.I | 双开口扳手 | 未找到无碰撞包络姿态 | 330 | 150 | 否 | 双级减压·切断·比例·止回（REG-205） [Reg205]；储氢床冷却液管路055｜BS-401·床路选择阀组—REG-205·双级减压·切断·比例·止回 [Pipe055]
MP.O | 双开口扳手 | 未找到无碰撞包络姿态 | 135 | 315 | 否 | 储氢床冷却液管路041｜BS-401·床路选择阀组—固态储氢模块（MH202） [Pipe041]
BPU.I | 双开口扳手 | 找到无碰撞包络姿态 | 285 | 15 | 是
BPU.O | 双开口扳手 | 未找到无碰撞包络姿态 | 120 | 300 | 否 | 分层托板支柱_BackPressure [Standoff_BackPressure_0]
HX.MI | 双开口扳手 | 未找到无碰撞包络姿态 | 105 | 285 | 否 | 低压缓冲计量切断（H2-201） [Mix]；主液热供分配（CH-301） [HotHeader]；活接固定端与反力六角（MX.I） [UnionBody_MX_I]；活接固定端与反力六角（HOT.AH） [UnionBody_HOT_AH]；活接管侧端与承压凸缘（HOT.AH） [UnionTail_HOT_AH]；活接端面密封圈（HOT.AH） [UnionSeal_HOT_AH]；活接可旋转螺母（HOT.AH） [UnionNut_HOT_AH]；主冷却液管路022｜CH-301·主液热供分配—HX-101·板翅空气调温器 [Pipe022]
HX.MO | 双开口扳手 | 未找到无碰撞包络姿态 | 330 | 150 | 否 | 双壁液液隔离（HX-301） [Isolation]；散热旁通三通（TV-302） [TV2]；活接固定端与反力六角（HX.BI） [UnionBody_HX_BI]；活接可旋转螺母（HX.BI） [UnionNut_HX_BI]；主冷却液管路034｜TV-301·余热分配三通—TV-302·散热旁通三通 [Pipe034]；主冷却液管路015｜TV-301·余热分配三通—HX-301·双壁液液隔离 [Pipe015]
HX.BI | 双开口扳手 | 未找到无碰撞包络姿态 | 150 | 330 | 否 | 双壁液液隔离（HX-301） [Isolation]；活接固定端与反力六角（HX.MO） [UnionBody_HX_MO]；活接可旋转螺母（HX.MO） [UnionNut_HX_MO]；活接固定端与反力六角（HX.BO） [UnionBody_HX_BO]；活接管侧端与承压凸缘（HX.BO） [UnionTail_HX_BO]；活接端面密封圈（HX.BO） [UnionSeal_HX_BO]；活接可旋转螺母（HX.BO） [UnionNut_HX_BO]；空气管路002｜CP-101·独立切向出风接管—HX-101·板翅空气调温器 [Pipe002]
HX.BO | 双开口扳手 | 未找到无碰撞包络姿态 | 150 | 330 | 否 | 双壁液液隔离（HX-301） [Isolation]；活接固定端与反力六角（HX.BI） [UnionBody_HX_BI]；活接可旋转螺母（HX.BI） [UnionNut_HX_BI]
TV1.I | 双开口扳手 | 找到无碰撞包络姿态 | 120 | 300 | 否
TV1.HX | 双开口扳手 | 未找到无碰撞包络姿态 | 90 | 270 | 否 | 主液热供分配（CH-301） [HotHeader]；分层安装托板_散热旁通三通（TV-302） [Subtray_TV2]
TV1.BY | 双开口扳手 | 未找到无碰撞包络姿态 | 105 | 285 | 否 | 分层安装托板_散热旁通三通（TV-302） [Subtray_TV2]
TV2.I | 双开口扳手 | 找到无碰撞包络姿态 | 75 | 345 | 是
TV2.RAD | 双开口扳手 | 未找到无碰撞包络姿态 | 330 | 150 | 否 | 散热旁通三通（TV-302） [TV2]；侧水室与框架·前后通风（R-301） [Radiator]；活接固定端与反力六角（TV2.BY） [UnionBody_TV2_BY]；活接可旋转螺母（TV2.BY） [UnionNut_TV2_BY]；活接可旋转螺母（TV2.SHORT） [UnionNut_TV2_SHORT]
TV2.BY | 双开口扳手 | 未找到无碰撞包络姿态 | 240 | 60 | 否 | 80根中空扁管·4排×20层（R-301） [RadiatorFlatTubes]；19层波纹翅片·0.18mm厚·10mm节距（R-301） [RadiatorCorrugatedFins]；主冷却液管路015｜TV-301·余热分配三通—HX-301·双壁液液隔离 [Pipe015]
TKM.FILL | 双开口扳手 | 找到无碰撞包络姿态 | 135 | 315 | 否
TKM.RET | 双开口扳手 | 找到无碰撞包络姿态 | 45 | 225 | 否
TKB.FILL | 双开口扳手 | 未找到无碰撞包络姿态 | 315 | 135 | 否 | 氢气管路011｜HCP-201·湿氢循环泵—H2-201·低压缓冲计量切断 [Pipe011]；储氢床冷却液管路045｜BS-401·床路选择阀组—固态储氢模块（MH203） [Pipe045]
TKB.RET | 双开口扳手 | 未找到无碰撞包络姿态 | 150 | 330 | 否 | 双级减压·切断·比例·止回（REG-206） [Reg206]
DI.I | 双开口扳手 | 未找到无碰撞包络姿态 | 15 | 195 | 否 | 去离子旁路（DI-301） [DI]；氢气管路010｜SEP-201·伴热阳极分水器—HCP-201·湿氢循环泵 [Pipe010]；氢气管路040｜XV/PCV/CV-202·床支路隔离比例止回—HM-201·六路止回合流 [Pipe040]；氢气管路011｜HCP-201·湿氢循环泵—H2-201·低压缓冲计量切断 [Pipe011]；氢气管路036｜XV/PCV/CV-201·床支路隔离比例止回—HM-201·六路止回合流 [Pipe036]
DI.O | 双开口扳手 | 未找到无碰撞包络姿态 | 15 | 195 | 否 | 氢气管路040｜XV/PCV/CV-202·床支路隔离比例止回—HM-201·六路止回合流 [Pipe040]；氢气管路011｜HCP-201·湿氢循环泵—H2-201·低压缓冲计量切断 [Pipe011]；氢气管路036｜XV/PCV/CV-201·床支路隔离比例止回—HM-201·六路止回合流 [Pipe036]
HOT.IN | 双开口扳手 | 找到无碰撞包络姿态 | 120 | 30 | 是
HOT.TV1 | 双开口扳手 | 未找到无碰撞包络姿态 | 135 | 315 | 否 | 主液热供分配（CH-301） [HotHeader]；活接固定端与反力六角（HOT.DI） [UnionBody_HOT_DI]；活接可旋转螺母（HOT.DI） [UnionNut_HOT_DI]
HOT.AH | 双开口扳手 | 未找到无碰撞包络姿态 | 135 | 315 | 否 | 主冷却液管路025｜HX-201·双壁氢伴热器—CR-301·主液回流汇集 [Pipe025]
HOT.HH | 双开口扳手 | 未找到无碰撞包络姿态 | 45 | 225 | 否 | 70节电堆·端板拉杆（STK-101） [Stack]
HOT.SEP | 双开口扳手 | 未找到无碰撞包络姿态 | 45 | 225 | 否 | 活接可旋转螺母（HOT.IN） [UnionNut_HOT_IN]；主冷却液管路034｜TV-301·余热分配三通—TV-302·散热旁通三通 [Pipe034]
HOT.DI | 双开口扳手 | 未找到无碰撞包络姿态 | 75 | 255 | 否 | 70节电堆·端板拉杆（STK-101） [Stack]；低压缓冲计量切断（H2-201） [Mix]
RET.MP | 双开口扳手 | 未找到无碰撞包络姿态 | 45 | 225 | 否 | 板翅空气调温器（HX-101） [AirHX]；主液回流汇集（CR-301） [ReturnHeader]；活接固定端与反力六角（RET.HH） [UnionBody_RET_HH]；活接可旋转螺母（RET.HH） [UnionNut_RET_HH]
RET.TV2 | 双开口扳手 | 未找到无碰撞包络姿态 | 90 | 270 | 否 | 主液回流汇集（CR-301） [ReturnHeader]；床路回流阀组（BR-401） [BedReturn]；活接固定端与反力六角（RET.SEP） [UnionBody_RET_SEP]；活接可旋转螺母（RET.SEP） [UnionNut_RET_SEP]；活接固定端与反力六角（BR.201） [UnionBody_BR_201]；活接管侧端与承压凸缘（BR.201） [UnionTail_BR_201]；活接端面密封圈（BR.201） [UnionSeal_BR_201]；活接可旋转螺母（BR.201） [UnionNut_BR_201]；活接端面密封圈（BR.TK） [UnionSeal_BR_TK]；储氢床冷却液管路038｜固态储氢模块（MH201）—BR-401·床路回流阀组 [Pipe038]；储氢床冷却液管路033｜TK-401·独立次路膨胀罐—BR-401·床路回流阀组 [Pipe033]
RET.TK | 双开口扳手 | 未找到无碰撞包络姿态 | 240 | 60 | 否 | 床路回流阀组（BR-401） [BedReturn]；双级减压·切断·比例·止回（REG-205） [Reg205]；活接固定端与反力六角（AH.E） [UnionBody_AH_E]；活接固定端与反力六角（BR.201） [UnionBody_BR_201]；活接管侧端与承压凸缘（BR.201） [UnionTail_BR_201]；活接端面密封圈（BR.201） [UnionSeal_BR_201]；活接可旋转螺母（BR.201） [UnionNut_BR_201]；储氢床冷却液管路038｜固态储氢模块（MH201）—BR-401·床路回流阀组 [Pipe038]；储氢床冷却液管路042｜固态储氢模块（MH202）—BR-401·床路回流阀组 [Pipe042]
RET.AH | 双开口扳手 | 未找到无碰撞包络姿态 | 285 | 105 | 否 | 六路止回合流（HM-201） [HydrogenHeader]；双级减压·切断·比例·止回（REG-205） [Reg205]；活接固定端与反力六角（AH.E） [UnionBody_AH_E]
RET.HH | 双开口扳手 | 未找到无碰撞包络姿态 | 30 | 210 | 否 | 板翅空气调温器（HX-101） [AirHX]
RET.SEP | 双开口扳手 | 未找到无碰撞包络姿态 | 315 | 135 | 否 | 主液回流汇集（CR-301） [ReturnHeader]；床路回流阀组（BR-401） [BedReturn]；空气接头固定半体（AH.I） [UnionBody_AH_I]；空气接头开口卡箍（AH.I） [UnionClamp_AH_I]；活接固定端与反力六角（RET.TV2） [UnionBody_RET_TV2]；活接可旋转螺母（RET.TV2） [UnionNut_RET_TV2]；活接固定端与反力六角（BR.REG） [UnionBody_BR_REG]；活接可旋转螺母（BR.REG） [UnionNut_BR_REG]
RET.DI | 双开口扳手 | 未找到无碰撞包络姿态 | 285 | 105 | 否 | 主液回流汇集（CR-301） [ReturnHeader]；床路回流阀组（BR-401） [BedReturn]；活接固定端与反力六角（AH.F） [UnionBody_AH_F]；活接固定端与反力六角（RET.TK） [UnionBody_RET_TK]；活接可旋转螺母（RET.TK） [UnionNut_RET_TK]；活接固定端与反力六角（BR.203） [UnionBody_BR_203]；活接管侧端与承压凸缘（BR.203） [UnionTail_BR_203]；活接端面密封圈（BR.203） [UnionSeal_BR_203]；活接可旋转螺母（BR.203） [UnionNut_BR_203]；储氢床冷却液管路046｜固态储氢模块（MH203）—BR-401·床路回流阀组 [Pipe046]
BS.IN | 双开口扳手 | 未找到无碰撞包络姿态 | 225 | 45 | 否 | 床路选择阀组（BS-401） [BedSupply]；储氢床冷却液管路055｜BS-401·床路选择阀组—REG-205·双级减压·切断·比例·止回 [Pipe055]
BS.201 | 双开口扳手 | 找到无碰撞包络姿态 | 210 | 150 | 是
BS.202 | 双开口扳手 | 未找到无碰撞包络姿态 | 285 | 105 | 否 | 活接固定端与反力六角（HM.204） [UnionBody_HM_204]；活接可旋转螺母（HM.204） [UnionNut_HM_204]
BS.203 | 双开口扳手 | 未找到无碰撞包络姿态 | 315 | 135 | 否 | 独立主路膨胀罐（TK-301） [TKmain]
BS.204 | 双开口扳手 | 未找到无碰撞包络姿态 | 255 | 75 | 否 | 湿氢循环泵（HCP-201） [Recirc]；床路选择阀组（BS-401） [BedSupply]；活接固定端与反力六角（BS.IN） [UnionBody_BS_IN]；活接可旋转螺母（BS.IN） [UnionNut_BS_IN]
BS.REG | 双开口扳手 | 未找到无碰撞包络姿态 | 315 | 135 | 否 | 活接固定端与反力六角（BS.201） [UnionBody_BS_201]；活接可旋转螺母（BS.201） [UnionNut_BS_201]
BR.OUT | 双开口扳手 | 未找到无碰撞包络姿态 | 150 | 330 | 否 | 70节电堆·端板拉杆（STK-101） [Stack]；储氢床冷却液管路041｜BS-401·床路选择阀组—固态储氢模块（MH202） [Pipe041]；储氢床冷却液管路042｜固态储氢模块（MH202）—BR-401·床路回流阀组 [Pipe042]
BR.201 | 双开口扳手 | 未找到无碰撞包络姿态 | 105 | 285 | 否 | 床路回流阀组（BR-401） [BedReturn]；活接固定端与反力六角（BR.TK） [UnionBody_BR_TK]；活接可旋转螺母（BR.TK） [UnionNut_BR_TK]；氢气管路051｜气态储氢瓶（GH205，35兆帕，概念容量22.174升）—REG-205·双级减压·切断·比例·止回 [Pipe051]
BR.202 | 双开口扳手 | 未找到无碰撞包络姿态 | 30 | 210 | 否 | 储氢床冷却液管路042｜固态储氢模块（MH202）—BR-401·床路回流阀组 [Pipe042]
BR.203 | 双开口扳手 | 未找到无碰撞包络姿态 | 30 | 210 | 否 | 活接固定端与反力六角（HM.205） [UnionBody_HM_205]；活接可旋转螺母（HM.205） [UnionNut_HM_205]；储氢床冷却液管路041｜BS-401·床路选择阀组—固态储氢模块（MH202） [Pipe041]；氢气管路051｜气态储氢瓶（GH205，35兆帕，概念容量22.174升）—REG-205·双级减压·切断·比例·止回 [Pipe051]；储氢床冷却液管路042｜固态储氢模块（MH202）—BR-401·床路回流阀组 [Pipe042]
BR.204 | 双开口扳手 | 未找到无碰撞包络姿态 | 15 | 195 | 否 | 70节电堆·端板拉杆（STK-101） [Stack]；活接可旋转螺母（RET.TK） [UnionNut_RET_TK]
BR.TK | 双开口扳手 | 未找到无碰撞包络姿态 | 15 | 195 | 否 | 床路回流阀组（BR-401） [BedReturn]；活接端面密封圈（BR.OUT） [UnionSeal_BR_OUT]；活接端面密封圈（BR.204） [UnionSeal_BR_204]；储氢床冷却液管路032｜BR-401·床路回流阀组—P-401·床泵·15升/分钟 [Pipe032]；储氢床冷却液管路050｜固态储氢模块（MH204）—BR-401·床路回流阀组 [Pipe050]
BR.REG | 双开口扳手 | 未找到无碰撞包络姿态 | 60 | 240 | 否 | 双级减压·切断·比例·止回（REG-205） [Reg205]；活接固定端与反力六角（BR.202） [UnionBody_BR_202]；活接管侧端与承压凸缘（BR.202） [UnionTail_BR_202]；活接端面密封圈（BR.202） [UnionSeal_BR_202]；氢气管路039｜固态储氢模块（MH202）—XV/PCV/CV-202·床支路隔离比例止回 [Pipe039]
HM.201 | 双开口扳手 | 未找到无碰撞包络姿态 | 135 | 315 | 否 | 储氢床冷却液管路045｜BS-401·床路选择阀组—固态储氢模块（MH203） [Pipe045]；储氢床冷却液管路049｜BS-401·床路选择阀组—固态储氢模块（MH204） [Pipe049]
HM.202 | 双开口扳手 | 未找到无碰撞包络姿态 | 45 | 225 | 否 | 氢气管路047｜固态储氢模块（MH204）—XV/PCV/CV-204·床支路隔离比例止回 [Pipe047]；储氢床冷却液管路049｜BS-401·床路选择阀组—固态储氢模块（MH204） [Pipe049]
HM.203 | 双开口扳手 | 找到无碰撞包络姿态 | 135 | 315 | 否
HM.204 | 双开口扳手 | 找到无碰撞包络姿态 | 135 | 315 | 否
HM.205 | 双开口扳手 | 未找到无碰撞包络姿态 | 105 | 285 | 否 | 双级减压·切断·比例·止回（REG-205） [Reg205]；活接固定端与反力六角（HM.201） [UnionBody_HM_201]；活接管侧端与承压凸缘（HM.201） [UnionTail_HM_201]；活接端面密封圈（HM.201） [UnionSeal_HM_201]；活接可旋转螺母（HM.201） [UnionNut_HM_201]
HM.206 | 双开口扳手 | 未找到无碰撞包络姿态 | 225 | 45 | 否 | 活接管侧端与承压凸缘（BS.202） [UnionTail_BS_202]；活接端面密封圈（BS.202） [UnionSeal_BS_202]；活接可旋转螺母（BS.202） [UnionNut_BS_202]；储氢床冷却液管路041｜BS-401·床路选择阀组—固态储氢模块（MH202） [Pipe041]
HM.OUT | 双开口扳手 | 未找到无碰撞包络姿态 | 150 | 330 | 否 | 六路止回合流（HM-201） [HydrogenHeader]；活接端面密封圈（HM.204） [UnionSeal_HM_204]；氢气管路048｜XV/PCV/CV-204·床支路隔离比例止回—HM-201·六路止回合流 [Pipe048]
RAD.I | 双开口扳手 | 找到无碰撞包络姿态 | 0 | 180 | 否
RAD.O | 双开口扳手 | 找到无碰撞包络姿态 | 0 | 270 | 是
V201.I | 双开口扳手 | 找到无碰撞包络姿态 | 225 | 315 | 是
V201.O | 双开口扳手 | 找到无碰撞包络姿态 | 165 | 345 | 否
V202.I | 双开口扳手 | 未找到无碰撞包络姿态 | 180 | 0 | 否 | 去离子旁路（DI-301） [DI]；活接固定端与反力六角（V202.O） [UnionBody_V202_O]；活接管侧端与承压凸缘（V202.O） [UnionTail_V202_O]；活接端面密封圈（V202.O） [UnionSeal_V202_O]；活接可旋转螺母（V202.O） [UnionNut_V202_O]
V202.O | 双开口扳手 | 找到无碰撞包络姿态 | 150 | 240 | 是
V203.I | 双开口扳手 | 未找到无碰撞包络姿态 | 240 | 60 | 否 | 床支路隔离比例止回（XV/PCV/CV-201） [Train201]；活接固定端与反力六角（V201.O） [UnionBody_V201_O]；活接管侧端与承压凸缘（V201.O） [UnionTail_V201_O]；活接端面密封圈（V201.O） [UnionSeal_V201_O]；氢气管路036｜XV/PCV/CV-201·床支路隔离比例止回—HM-201·六路止回合流 [Pipe036]
V203.O | 双开口扳手 | 找到无碰撞包络姿态 | 165 | 225 | 是
V204.I | 双开口扳手 | 未找到无碰撞包络姿态 | 30 | 210 | 否 | 湿氢循环泵（HCP-201） [Recirc]；去离子旁路（DI-301） [DI]
V204.O | 双开口扳手 | 找到无碰撞包络姿态 | 165 | 225 | 是
REG205.I | 双开口扳手 | 找到无碰撞包络姿态 | 45 | 225 | 否
REG205.O | 双开口扳手 | 找到无碰撞包络姿态 | 225 | 135 | 是
REG205.PRD | 双开口扳手 | 未找到无碰撞包络姿态 | 15 | 195 | 否 | 氢气管路006｜HM-201·六路止回合流—HX-201·双壁氢伴热器 [Pipe006]
REG205.S | 双开口扳手 | 未找到无碰撞包络姿态 | 30 | 210 | 否 | 氢气管路006｜HM-201·六路止回合流—HX-201·双壁氢伴热器 [Pipe006]；空气管路058｜AF-101·外界进气滤清器·双腔壳体—外界进气接口 [Pipe058]
REG205.R | 双开口扳手 | 未找到无碰撞包络姿态 | 195 | 15 | 否 | 储氢床冷却液管路055｜BS-401·床路选择阀组—REG-205·双级减压·切断·比例·止回 [Pipe055]
REG206.I | 双开口扳手 | 找到无碰撞包络姿态 | 180 | 0 | 否
REG206.O | 双开口扳手 | 找到无碰撞包络姿态 | 180 | 120 | 是
REG206.PRD | 双开口扳手 | 找到无碰撞包络姿态 | 75 | 165 | 是
REG206.S | 双开口扳手 | 未找到无碰撞包络姿态 | 30 | 210 | 否 | 氢气管路054｜REG-206·双级减压·切断·比例·止回—HM-201·六路止回合流 [Pipe054]；氢气管路035｜固态储氢模块（MH201）—XV/PCV/CV-201·床支路隔离比例止回 [Pipe035]
REG206.R | 双开口扳手 | 未找到无碰撞包络姿态 | 210 | 30 | 否 | 氢气管路035｜固态储氢模块（MH201）—XV/PCV/CV-201·床支路隔离比例止回 [Pipe035]
TV2.SHORT | 双开口扳手 | 找到无碰撞包络姿态 | 0 | 180 | 否
AIR_IN.PORT | 双套筒 | 找到无碰撞包络姿态 | 75 |  | 否
AIR_OUT.PORT | 双套筒 | 找到无碰撞包络姿态 | 15 |  | 否
PURGE.PORT | 双开口扳手 | 找到无碰撞包络姿态 | 165 | 225 | 是
VENT205.PORT | 双开口扳手 | 未找到无碰撞包络姿态 | 330 | 150 | 否 | 气瓶206安全放散外接管 [External_VENT206]
VENT206.PORT | 双开口扳手 | 未找到无碰撞包络姿态 | 30 | 210 | 否 | 电气层独立支柱003 [PowerRackPost_3]
BED_FILL.PORT | 双开口扳手 | 找到无碰撞包络姿态 | 30 | 210 | 否

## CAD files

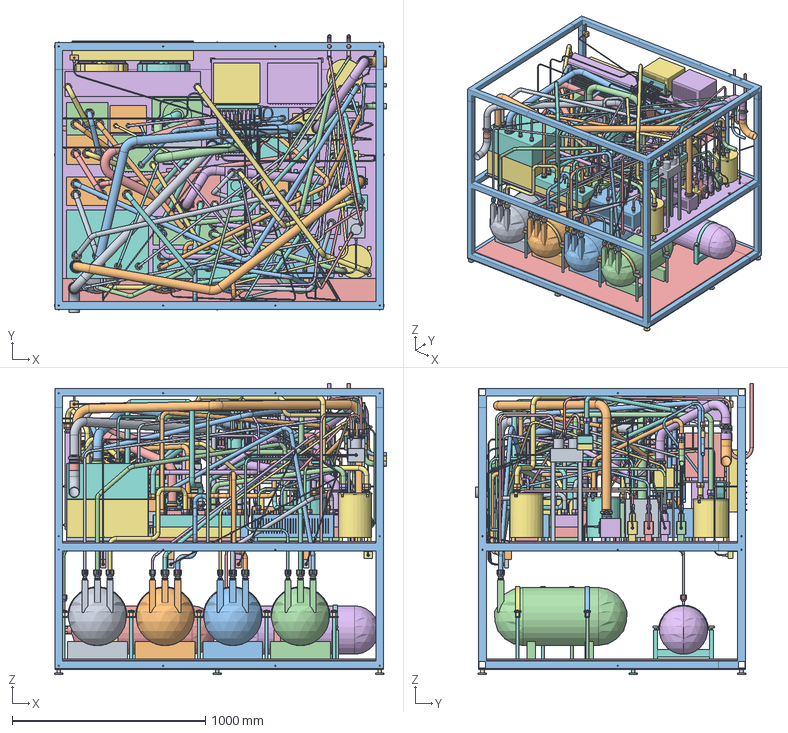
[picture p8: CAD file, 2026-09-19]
models/R12/3D燃料电池模型.FCStd
1717.0 x 1435.9 x 1505.0 mm
固态储氢模块承托鞍座（MH201）
固态储氢模块承托鞍座（MH202）
固态储氢模块承托鞍座（MH203）
固态储氢模块承托鞍座（MH204）
电池承托板
控制器与变换器共用上层托板
电气层独立支柱
电气层独立支柱001
电气层独立支柱002
电气层独立支柱003
电池托板承重套座
电池托板承重套座001
电池托板承重套座002
电池托板承重套座003
分层安装托板_双壁氢伴热器（HX-201）
分层托板支柱_H2HX
分层托板支柱_H2HX001
分层托板支柱_H2HX002
分层托板支柱_H2HX003
分层安装托板_低压缓冲计量切断（H2-201）
分层托板支柱_Mix
分层托板支柱_Mix001
分层托板支柱_Mix002
分层托板支柱_Mix003
分层安装托板_阴极背压阀（BPV-101）
分层托板支柱_BackPressure
分层托板支柱_BackPressure001
分层托板支柱_BackPressure002
分层托板支柱_BackPressure003
分层安装托板_散热旁通三通（TV-302）
分层托板支柱_TV2
分层托板支柱_TV001
分层托板支柱_TV002
分层托板支柱_TV003
分层安装托板_主液热供分配（CH-301）
分层托板支柱_HotHeader
分层托板支柱_HotHeader001
分层托板支柱_HotHeader002
分层托板支柱_HotHeader003
线束汇接盒前面固定板
固态储氢模块（MH201）
固态储氢模块（MH202）
固态储氢模块（MH203）
固态储氢模块（MH204）
气态储氢瓶（GH205，35兆帕，概念容量22.174升）
气态储氢瓶（GH206，35兆帕，概念容量22.174升）
固态储氢模块内部换热管（MH201）
固态储氢模块内部集流管（MH201）
固态储氢模块内部强化换热翅片（MH201）
70节电堆·端板拉杆（STK-101）
外界进气滤清器·双腔壳体（AF-101）
离心鼓风机·蜗壳·轴向入口·侧向出口（CP-101）
板翅空气调温器（HX-101）
空气截止与计量（XV-101）
阴极背压阀（BPV-101）
独立轴向进风过渡接管（CP-101）
独立切向出风接管（CP-101）
12片后弯扭转叶轮·独立转子（CP-101）
折叠滤芯·多孔介质示意（AF-101）
滤芯密封边框（AF-101）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

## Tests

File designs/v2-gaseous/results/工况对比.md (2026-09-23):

| 工况 | 毛功率 kW | 电流 A | 冷却热负荷 kW | 冷却 L/min | 散热器迎风 m² | 风量 m³/h | 氢耗 kg/h | 需瓶水容积 L |
|---|---:|---:|---:|---:|---:|---:|---:|---:|
| baseline | 6.200 | 69.47 | 5.200 | 17.84 | 0.344 | 3712 | 0.321 | 66.2 |
| lower_voltage | 6.371 | 76.48 | 6.146 | 21.08 | 0.406 | 4388 | 0.353 | 72.7 |
| higher_pressure_drop | 7.027 | 78.74 | 5.915 | 20.29 | 0.391 | 4223 | 0.363 | 74.8 |
| weaker_radiator | 6.438 | 72.14 | 5.405 | 18.54 | 0.480 | 5187 | 0.333 | 68.7 |
| combined_adverse | 8.151 | 97.85 | 7.956 | 27.29 | 0.707 | 7636 | 0.451 | 92.6 |
